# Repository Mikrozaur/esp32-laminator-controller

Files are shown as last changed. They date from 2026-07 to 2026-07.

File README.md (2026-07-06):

# ESP32 Roll Laminator Controller

[Русская версия](README_ru.md)

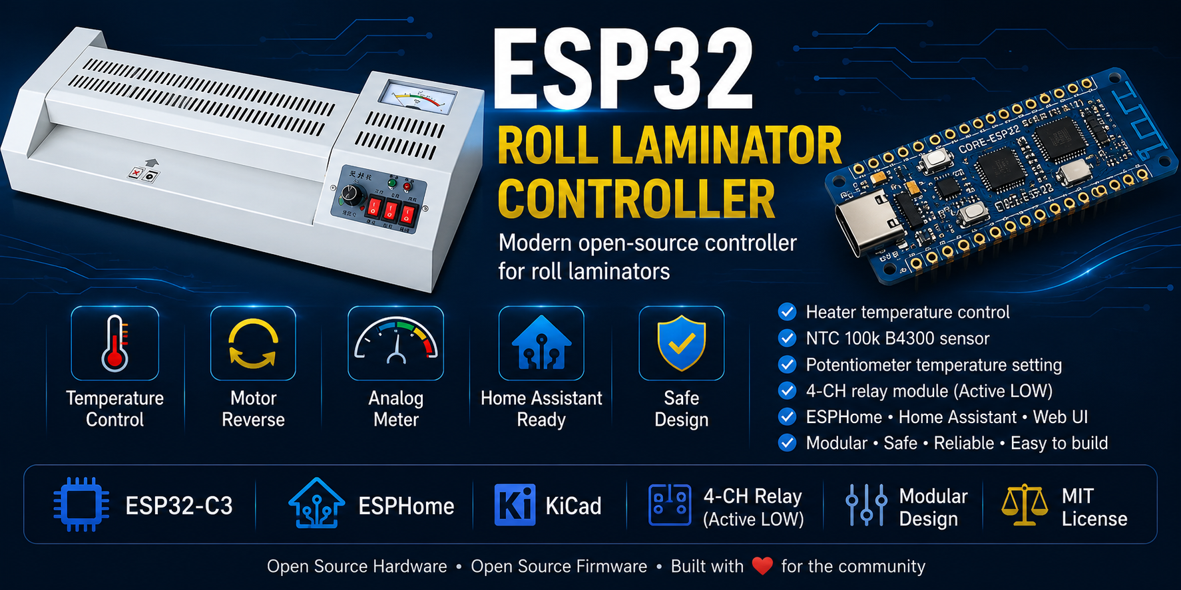
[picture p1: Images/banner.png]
Banner


Modern replacement controller for inexpensive roll laminators based on **ESP32-C3** and **ESPHome**.

The project replaces the original controller board with a fully programmable, modular, and repairable solution built from standard components.

---

## Project Goals

- High reliability
- Electrical safety
- Easy maintenance and repair
- Use of widely available components
- Complete separation of high-voltage and low-voltage circuits
- Home Assistant integration
- Open-source hardware and firmware

---

## Current Status

**Version:** 1.0

✔ Hardware completed

✔ ESPHome firmware completed

✔ Control algorithms completed

✔ Preliminary temperature calibration completed

⏳ Fine temperature calibration and long-term testing remain.

---

## Main Features

- Heater temperature control
- Motor forward / reverse control
- Temperature adjustment using a potentiometer
- Analog temperature meter support
- Two status LEDs (PREHEAT / WORK)
- NTC 100k B4300 temperature sensor
- Home Assistant integration through ESPHome
- Simple modular architecture
- Standard relay module support
- Easy assembly on perfboard

---

## Safety

The controller was designed with electrical safety as one of its primary goals.

Unlike the original controller board, **all high-voltage (220 VAC) circuitry has been removed from the control electronics**.

The ESP32 board, switches, potentiometer, LEDs, and temperature sensor operate exclusively from **3.3 V / 5 V**.

The only part connected to mains voltage is the external **4-channel relay module**, which switches:

- Heater
- Motor power
- Motor direction

This architecture significantly improves safety, simplifies debugging, and makes future repairs much easier.

---

## Hardware
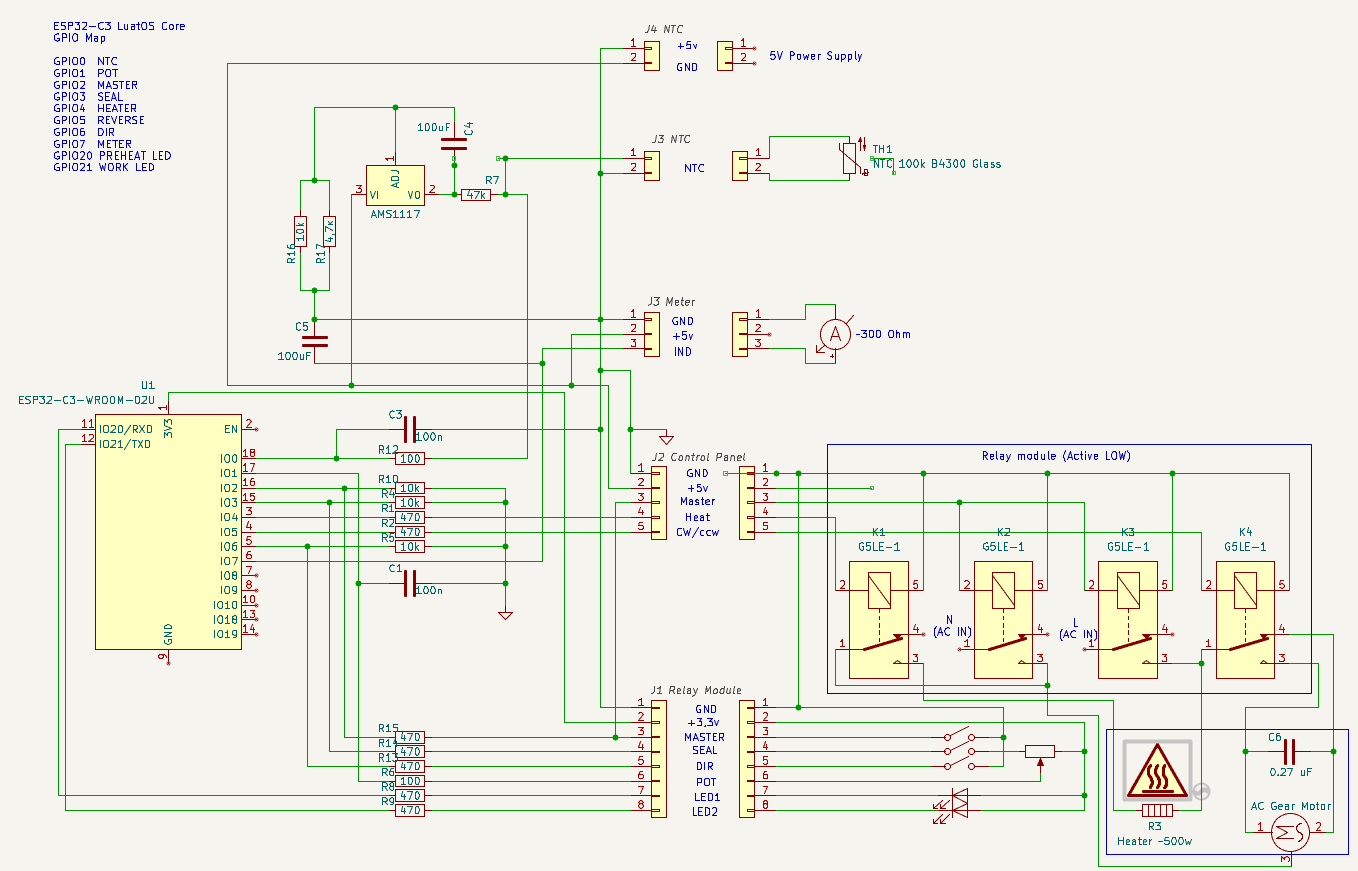
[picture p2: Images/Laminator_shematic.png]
  
Controller:

- ESP32-C3 LuatOS Core
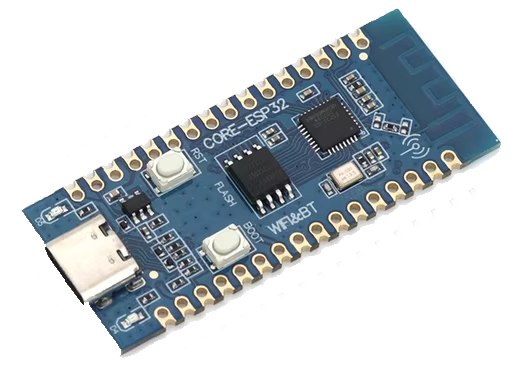
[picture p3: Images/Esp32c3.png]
    

Temperature sensor:

- Glass NTC 100k B4300

Voltage regulator:

- AMS1117-3.3

Relay module:#

- Standard 4-channel relay board
- Active LOW inputs

---

## GPIO Mapping

| GPIO | Function |
|---|---|
| GPIO0 | NTC temperature sensor |
| GPIO1 | Potentiometer |
| GPIO2 | MASTER switch |
| GPIO3 | SEAL switch |
| GPIO4 | Heater relay |
| GPIO5 | Reverse relay |
| GPIO6 | Direction switch |
| GPIO7 | Analog meter (PWM) |
| GPIO20 | PREHEAT LED |
| GPIO21 | WORK LED |

Unused GPIO:

- GPIO8
- GPIO9
- GPIO12
- GPIO13
- GPIO18
- GPIO19

---

## Relay Module

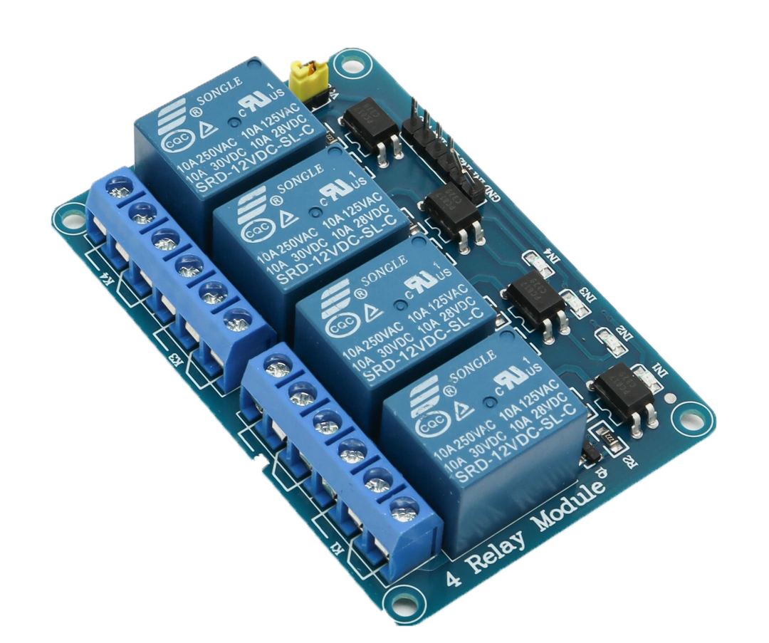
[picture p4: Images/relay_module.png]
  

The project uses a standard **4-channel Active LOW relay module**.

Logic:

- GPIO LOW → Relay ON
- GPIO HIGH → Relay OFF

ESPHome configuration:

- `inverted: true`
- `restore_mode: ALWAYS_OFF`

This guarantees that all relays remain OFF immediately after power-up or reset.

---

## Repository Structure

```
Firmware/
    ESPHome YAML

Hardware/
    Schematics
    PCB
    KiCad project

docs/
    Technical specification
    Calibration notes

Images/
    Photos
    Schematics
```

---

## Requirements

- ESPHome
- Home Assistant (optional)
- ESP32-C3
- 5V power supply
- Standard 4-channel relay module

---

## Future Improvements

- Final temperature calibration
- Long-term reliability testing
- PCB revision
- Optional WS2812 status indicator
- Additional Home Assistant entities

---

## License

This project is released under the MIT License.

Feel free to use, modify and improve it.

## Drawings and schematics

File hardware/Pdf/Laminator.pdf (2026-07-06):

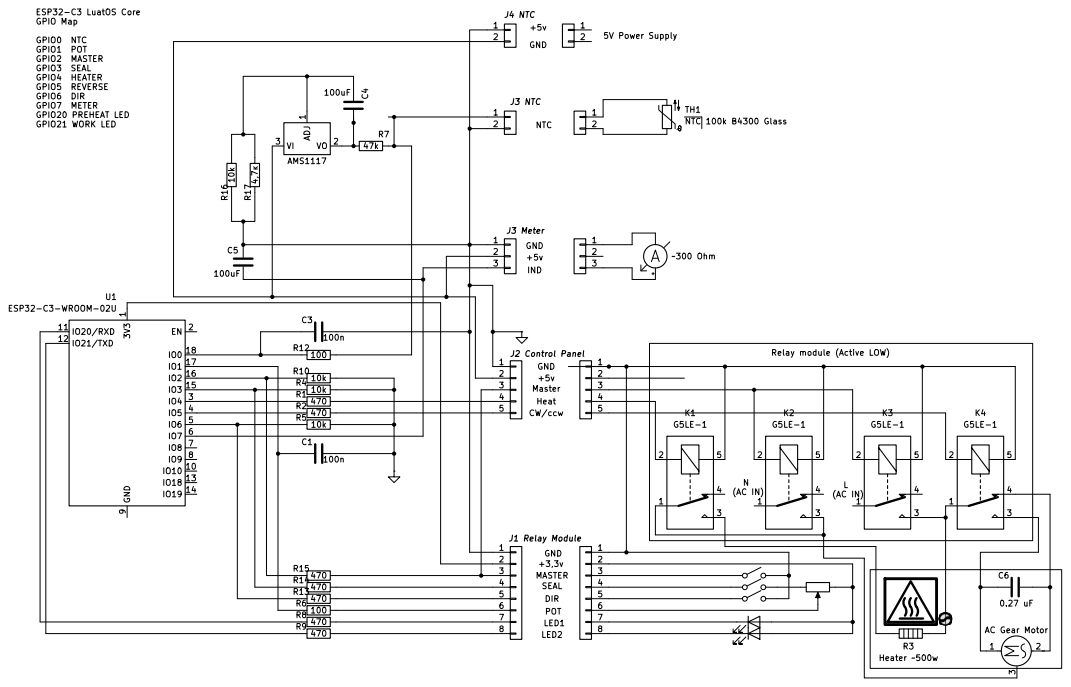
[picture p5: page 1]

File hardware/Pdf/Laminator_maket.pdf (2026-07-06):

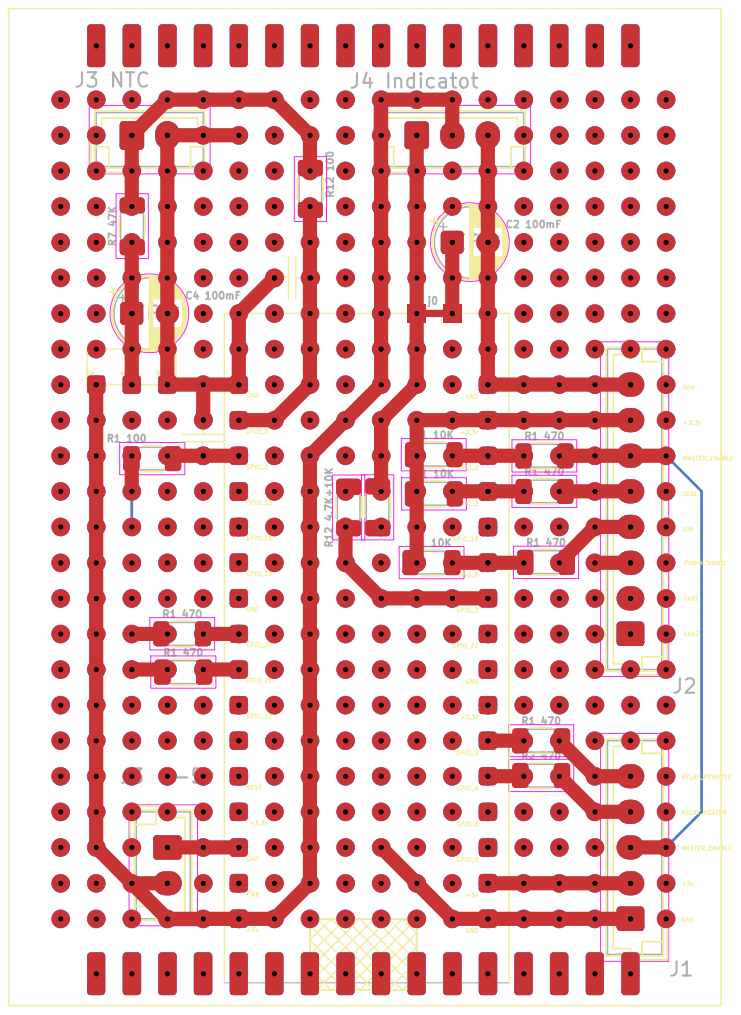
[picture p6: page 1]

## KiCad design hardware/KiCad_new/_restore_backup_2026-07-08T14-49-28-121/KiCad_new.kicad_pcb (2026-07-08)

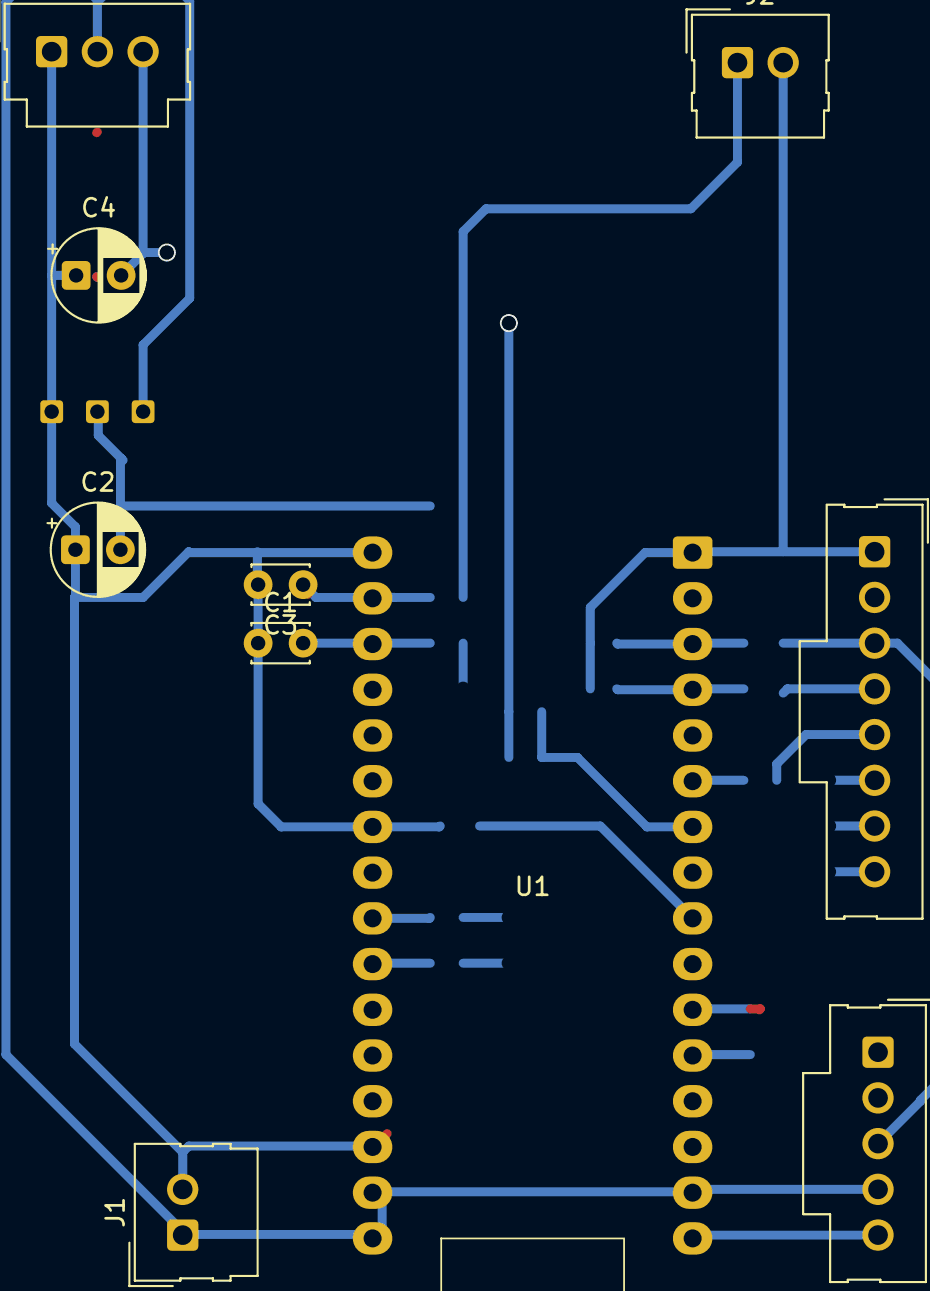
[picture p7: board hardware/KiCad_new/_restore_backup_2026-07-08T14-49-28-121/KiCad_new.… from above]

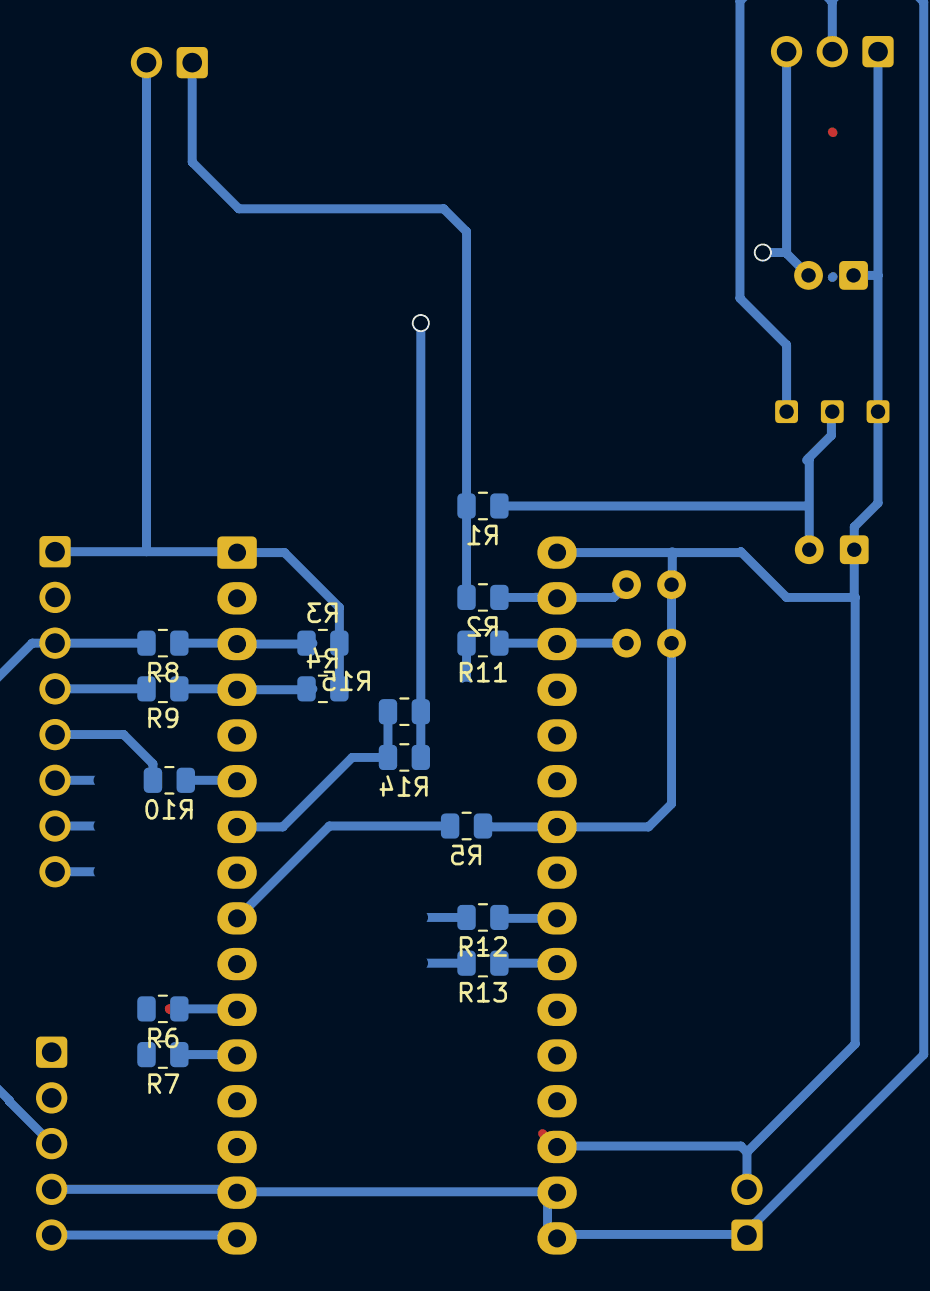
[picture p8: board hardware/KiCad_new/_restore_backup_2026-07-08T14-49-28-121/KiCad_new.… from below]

Board: 2 copper layers, 26 parts (15 on the bottom side), 24 nets.

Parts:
C1, C3: 100n; C_Disc_D3.0mm_W2.0mm_P2.50mm
C2, C4: 100uF; CP_Radial_D5.0mm_P2.50mm
J1: J1 Power; Molex_SL_171971-0002_1x02_P2.54mm_Vertical
J2: J2 NTC; Molex_SL_171971-0002_1x02_P2.54mm_Vertical
J3: Meter; Molex_SL_171971-0003_1x03_P2.54mm_Vertical
J4: Relay Module; Molex_SL_171971-0005_1x05_P2.54mm_Vertical
J5: Control Panel; Molex_SL_171971-0008_1x08_P2.54mm_Vertical
R1: 47k; R_0805_2012Metric
R2, R11: 100; R_0805_2012Metric
R3, R4, R5, R15: 10k; R_0805_2012Metric
R6, R7, R8, R9, R10, R12, R13: 470; R_0805_2012Metric
R14: 4,7к; R_0805_2012Metric
U1: ESP32-C3 Dev Board; ESP32-C3_LuatOS
U2: AMS1117; Ams1117 module

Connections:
GND: C1.1, C2.1, C3.2, C4.1, J1.2, J2.2, J3.1, J4.5, J5.1, R3.2, R4.2, R5.2, U1.1 (GND), U1.9 (GND), U1.16 (GND), U1.17 (GND), U1.23 (GND), U1.30 (GND), U2.3 (Gnd)
unnamed: J1.1, J3.2, J4.4, U1.15 (+5v), U1.31 (PWR), U1.32 (+5v), U2.1 (VIn_5v)
unnamed: J2.1, R1.2, R2.2
unnamed: C4.2, J3.3, R14.1, R15.1
unnamed: J4.1, R7.2
unnamed: J4.2, R6.2
unnamed: J4.3, J5.3, R8.2
unnamed: J5.2, U1.10 (+3.3v)
unnamed: J5.4, R9.2
unnamed: J5.5, R10.2
unnamed: J5.6, R11.2
unnamed: J5.7, R12.2
unnamed: J5.8, R13.2
unnamed: C3.1, R2.1, U1.18 (GPIO0)
unnamed: C1.2, R11.1, U1.19 (GPIO1)
unnamed: R3.1, R8.1, U1.3 (GPIO2)
unnamed: R4.1, R9.1, U1.4 (GPIO3)
unnamed: R7.1, U1.12 (GPIO4)
unnamed: R6.1, U1.11 (GPIO5)
unnamed: R5.1, R10.1, U1.6 (GPIO6)
unnamed: R14.2, R15.2, U1.7 (GPIO7)
unnamed: R13.1, U1.26 (GPIO13)
unnamed: R12.1, U1.25 (GPIO21)
unnamed: C2.2, R1.1, U2.2 (VOut_3.3v)

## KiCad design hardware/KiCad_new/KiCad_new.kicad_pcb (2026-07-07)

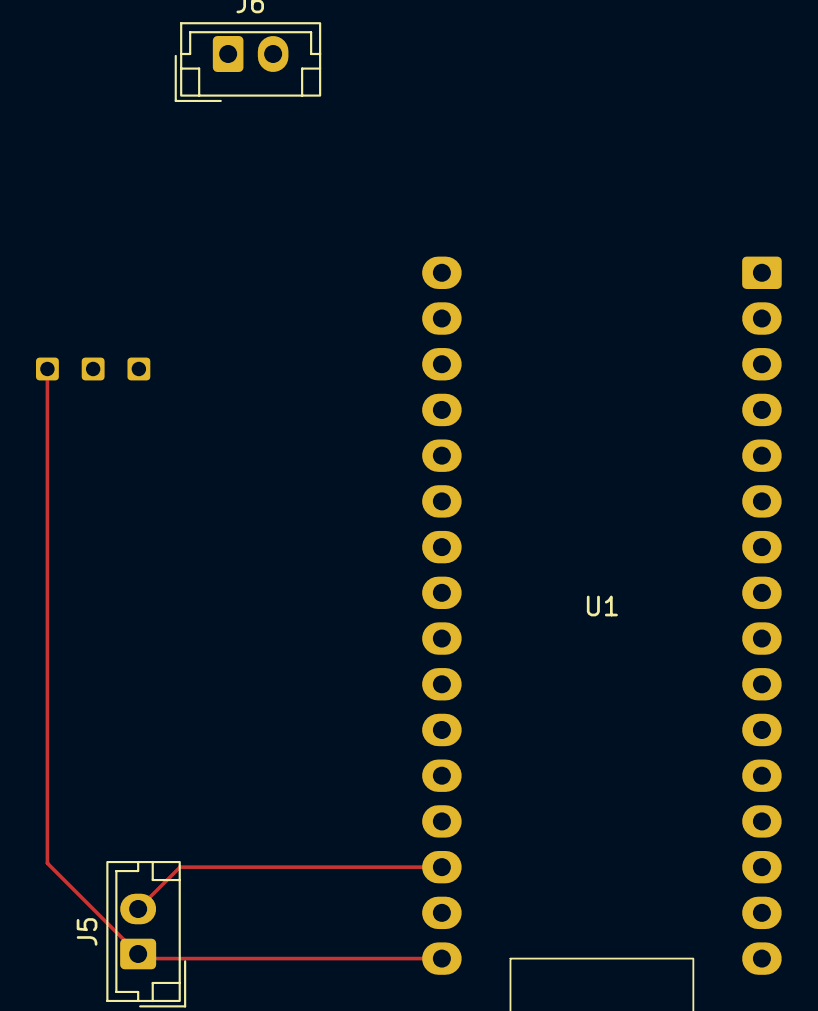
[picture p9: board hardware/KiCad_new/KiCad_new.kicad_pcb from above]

Board: 2 copper layers, 4 parts (0 on the bottom side), 3 nets.

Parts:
J5: Power; JST_EH_B2B-EH-A_1x02_P2.50mm_Vertical
J6: NTC; JST_EH_B2B-EH-A_1x02_P2.50mm_Vertical
P1: Ams1117 module
U1: ESP32-C3 LuatOS; ESP32-C3_LuatOS

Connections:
unnamed: J5.1, P1.1 (VIn_5v), U1.32 (+5v)
unnamed: J5.2, J6.1, U1.17 (GND), U1.24 (GND), U1.30 (GND)
unnamed: J6.2, U1.18 (GPIO0)

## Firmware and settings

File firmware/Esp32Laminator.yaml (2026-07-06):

# ==========================================================
# ESP32 Roll Laminator Controller
#
# Firmware Version : 1.0
# Framework        : ESPHome
# Target           : ESP32-C3
#
# https://github.com/Mikrozaur/esp32-laminator-controller
# ==========================================================

esphome:
  name: esp32laminator
  friendly_name: Laminator

  on_boot:
    priority: -10
    then:
      - component.update: current_temperature
      - script.execute: update_direction
      - script.execute: update_seal

esp32:
  board: esp32-c3-devkitm-1
  framework:
    type: esp-idf

preferences:
  flash_write_interval: 60s

logger:
   level: WARN

# =========================
# WIFI
# =========================
wifi:
  ssid: !secret wifi_ssid_base
  password: !secret wifi_password_base
  power_save_mode: LIGHT
  output_power: 12dB
#  manual_ip:
#    static_ip: 192.168.x.x
#    gateway: 192.168.x.x
#    subnet: 255.255.255.0

  ap:
    ssid: "esp32mini Fallback"
    password: !secret ap_password

captive_portal:


# =========================
# API
# =========================
api:
  encryption:
    key: !secret api_key
ota:
  - platform: esphome
    password: !secret ota_password
web_server:
  port: 80 


globals:
  - id: display_mode
    type: bool
    restore_value: no
    initial_value: "false"


# ==========================================================
# DIGITAL INPUTS
# ==========================================================
binary_sensor:

# --------------------------------------------------------
# MASTER
# Main power switch
#
# LOW  = OFF
# HIGH = ON (due to inverted logic)
# --------------------------------------------------------

  - platform: gpio
    id: master_sw
    name: "MASTER"

    pin:
      number: GPIO2
      mode:
        input: true
      inverted: true

  # --------------------------------------------------------
  # SEAL
  # Heating enable switch
  # --------------------------------------------------------
  - platform: gpio
    id: seal_sw
    name: "SEAL"

    pin:
      number: GPIO6
      mode:
        input: true
      inverted: true
    on_state:
      then:
        - script.execute: update_seal


# --------------------------------------------------------
# DIR
# Motor direction switch
# --------------------------------------------------------

  - platform: gpio
    id: dir_sw
    name: "DIR"
    internal: true
    pin:
      number: GPIO3
      mode:
        input: true
 #     inverted: true
    on_state:
      then:
        - script.execute: update_direction
# ==========================================================
# RELAY OUTPUTS
# Currently controlled manually from Home Assistant
# ==========================================================
switch:

# --------------------------------------------------------
# Heater relay
# --------------------------------------------------------
  - platform: gpio
    id: heater_relay
    name: "Heater Relay"
    pin: 
      number: GPIO5
      inverted: true
    restore_mode: ALWAYS_OFF
# --------------------------------------------------------
# Motor reverse relay
# --------------------------------------------------------
  - platform: gpio
    id: reverse_relay
    name: "Reverse Relay"
    internal: true
    pin:
      number: GPIO4
      inverted: true
    restore_mode: ALWAYS_OFF

# ==========================================================
# OUTPUTS
# ==========================================================
output:

# --------------------------------------------------------
# PREHEAT LED
# Active LOW
# --------------------------------------------------------
  - platform: gpio
    id: led_preheat_out

    pin:
      number: GPIO21
      inverted: true

# --------------------------------------------------------
# WORK LED
# Active LOW
# --------------------------------------------------------
  - platform: gpio
    id: led_work_out

    pin:
      number: GPIO20
      inverted: true

# --------------------------------------------------------
# Analog temperature meter
# PWM output
# Can be replaced with WS2812 LEDs in future versions
# --------------------------------------------------------
  - platform: ledc
    id: meter_pwm

    pin: GPIO7

    frequency: 1000 Hz


# ==========================================================
# STATUS LEDS
# ==========================================================
light:

  # --------------------------------------------------------
  # PREHEAT
  # --------------------------------------------------------
  - platform: binary

    id: led_preheat
    name: "LED PREHEAT"

    output: led_preheat_out

  # --------------------------------------------------------
  # WORK
  # --------------------------------------------------------
  - platform: binary

    id: led_work
    name: "LED WORK"

    output: led_work_out


# ==========================================================
# ANALOG SENSORS
# ==========================================================
sensor:
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

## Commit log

2026-07-07 Some changes in shematic
    [KiCad_new.kicad_pcb, KiCad_new.kicad_sch]
2026-07-08 Create PCB
    [KiCad_new.kicad_pcb, KiCad_new.kicad_sch, Main.kicad_sch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]
